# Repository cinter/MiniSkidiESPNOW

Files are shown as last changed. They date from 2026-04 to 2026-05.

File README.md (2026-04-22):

# MiniSkidiESPNOW
Branch of ProfBoots MiniSkidi code to support a custom controller with control via ESPNOW wifi. The code uploaded here will be working code, so don't worry if there are few commits. I use this repo as a backup of known good states. I am not a coder, this is all generated with Gemini and checked by Codex.

## 3D files
The original controller design can be found on OnShape [here](https://cad.onshape.com/documents/6bafb625ffbc5bb075599570/w/3596931d871cc26ccb4a224e/e/206217da13ada2750408ef04).

Printable files are [here](https://www.printables.com/model/1694698-miniskidi-controller), and I'll try to keep a list of components below.

## Components
Custom circuit board: KiCad files can be downloaded from Controller_V2 here. Ordered from JLCPCB, but PCBWay and others work too.  
Joystick: [Analog 2-axis Thumb Joystick with Select Button + Breakout Board](https://thepihut.com/products/adafruit-analog-2-axis-thumb-joystick-with-select-button-breakout-board)  
ESP32-C3 XIAO dev board: [Seeed XIAO ESP32C3](https://thepihut.com/products/seeed-xiao-esp32c3?variant=53975115694465)  
Battery: [3.7V 600mAh Battery](https://www.amazon.co.uk/dp/B0DB1X3RK7)  
Toggle switch: [5mm	toggle](https://www.amazon.co.uk/dp/B088R3GYWP)  
Tacctile buttons: [PCB buttons, these or similar](https://www.mouser.co.uk/ProductDetail/Same-Sky/TS04-66-85-BK-160-SMT-TR?qs=VJzv269c%252BPaHwNn0xD14PA%3D%3D)  
LED: [Neopixel LED](https://thepihut.com/products/neopixel-5050-rgb-led-with-integrated-driver-chip-10-pack)  
Cap for NeoPixel: [0.1uF Capacitor](https://uk.farnell.com/vishay/k104k15x7rf5tl2/cap-0-1-f-50v-10-x7r/dp/2860097)  
Light pipe:	[3mm, 1mm length](https://uk.farnell.com/mentor/1282-1405/light-pipe-1pipe-11mm-l-panel/dp/4562818)

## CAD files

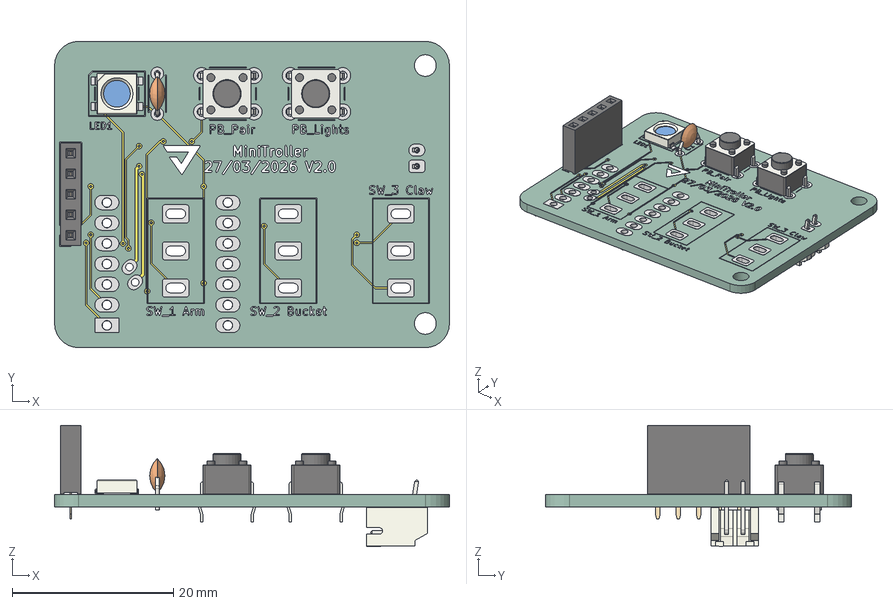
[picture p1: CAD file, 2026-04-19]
Controller_V2/Controller_V2.step
49.0 x 38.0 x 15.0 mm
C_Disc_D4.3mm_W1.9mm_P5.00mm
PinSocket_1x05_P2.54mm_Vertical
LED_Inolux_IN-PI554FCH_PLCC4_5.0x5.0mm_P3.2mm
SW_PUSH_6mm_H5mm x 2
JST_PH_S2B-PH-K_1x02_P2.00mm_Horizontal
Controller_V2_copper
Controller_V2_pad
Controller_V2_via
Controller_V2_silkscreen x 2
Controller_V2_PCB

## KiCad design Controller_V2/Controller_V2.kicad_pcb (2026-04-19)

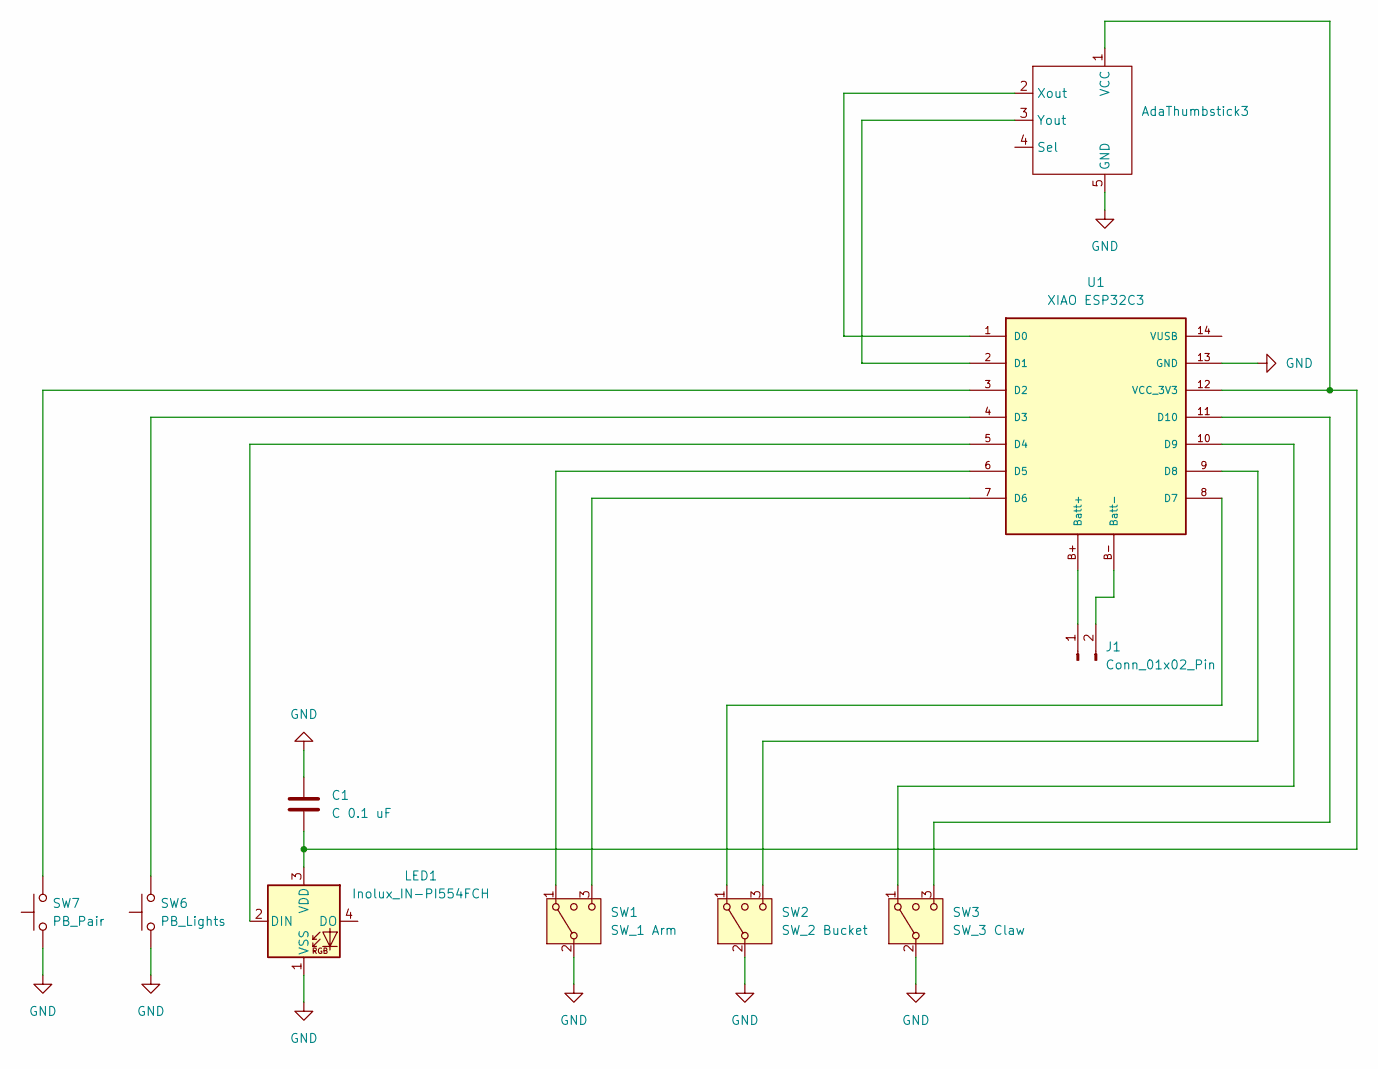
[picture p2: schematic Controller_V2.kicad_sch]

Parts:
AdaThumbstick3: PinSocket_1x05_P2.54mm_Vertical
C1: C 0.1 uF; C_Disc_D4.3mm_W1.9mm_P5.00mm
J1: Conn_01x02_Pin; JST_PH_S2B-PH-K_1x02_P2.00mm_Horizontal
LED1: Inolux_IN-PI554FCH; LED_Inolux_IN-PI554FCH_PLCC4_5.0x5.0mm_P3.2mm
SW1: SW_1 Arm; Toggle switch
SW2: SW_2 Bucket; Toggle switch
SW3: SW_3 Claw; Toggle switch
SW6: PB_Lights; SW_PUSH_6mm_H5mm
SW7: PB_Pair; SW_PUSH_6mm_H5mm
U1: XIAO ESP32C3

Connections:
GND: AdaThumbstick3.5 (GND), C1.1, LED1.1 (VSS), SW1.2 (3), SW2.2 (3), SW3.2 (3), SW6.1, SW7.1, U1.13 (GND)
unnamed: AdaThumbstick3.1 (VCC), C1.2, LED1.3 (VDD), U1.12 (VCC_3V3)
unnamed: AdaThumbstick3.2 (Xout), U1.1 (D0)
unnamed: AdaThumbstick3.3 (Yout), U1.2 (D1)
unnamed: J1.1, U1.B+ (Batt+)
unnamed: J1.2, U1.B- (Batt-)
unnamed: LED1.2 (DIN), U1.5 (D4)
unnamed: SW1.3 (4), U1.7 (D6)
unnamed: SW2.3 (4), U1.9 (D8)
unnamed: SW3.3 (4), U1.11 (D10)
unnamed: SW7.2, U1.3 (D2)
unnamed: SW6.2, U1.4 (D3)
unnamed: SW1.1, U1.6 (D5)
unnamed: SW2.1, U1.8 (D7)
unnamed: SW3.1, U1.10 (D9)

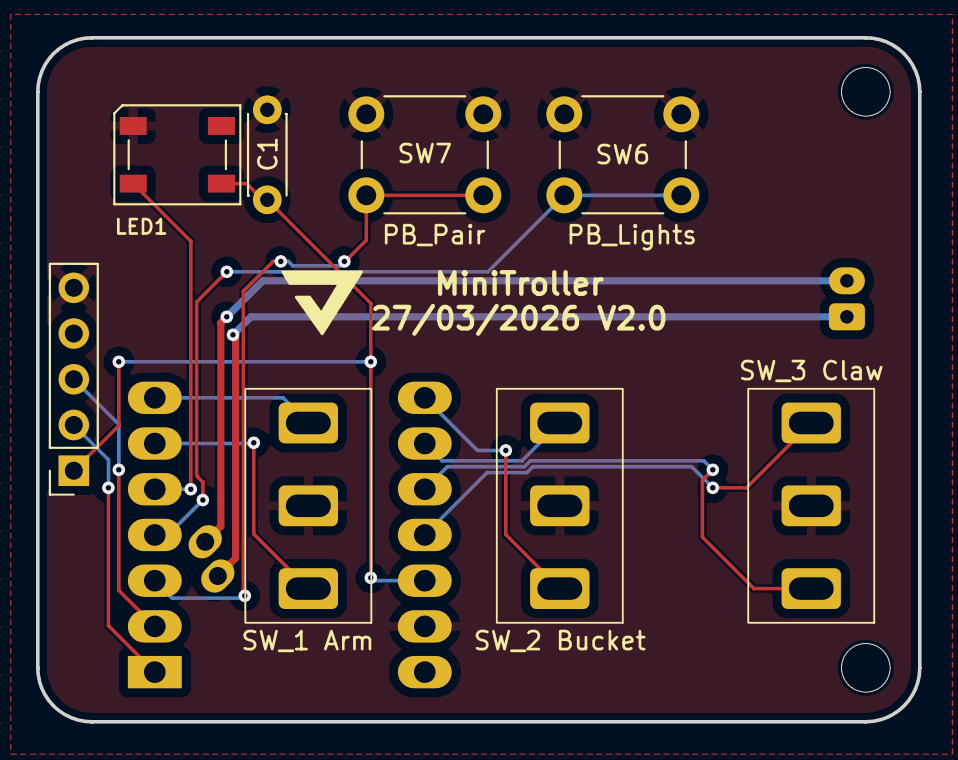
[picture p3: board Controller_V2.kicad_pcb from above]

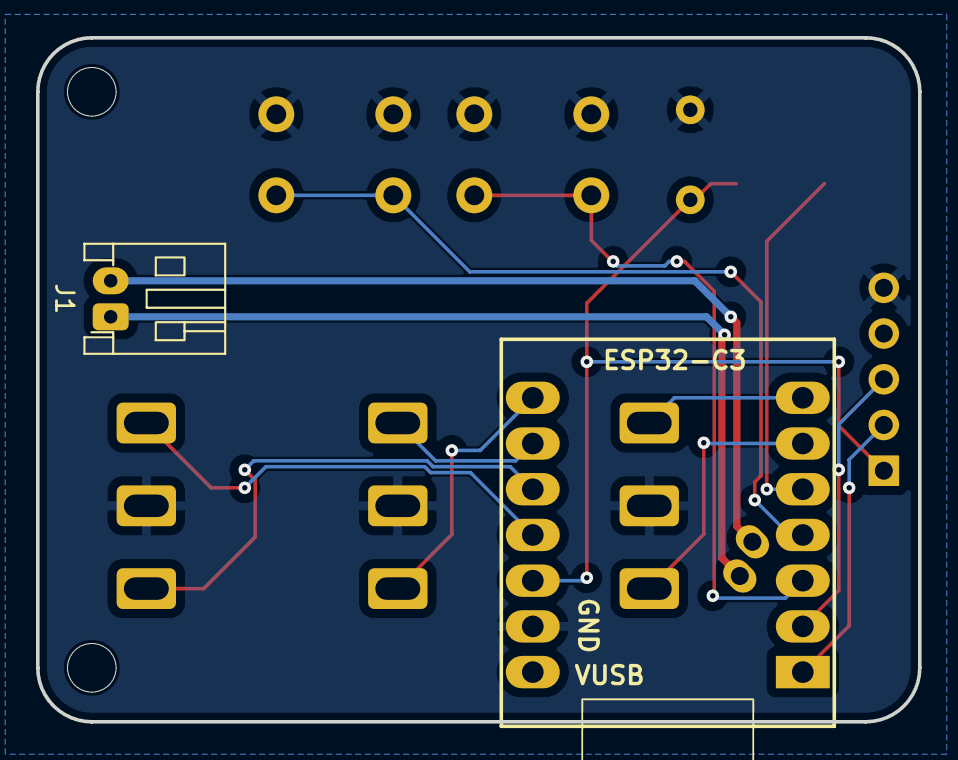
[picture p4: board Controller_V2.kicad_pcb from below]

Board: 2 copper layers, 49.0 x 38.0 mm, 10 parts (2 on the bottom side), 15 nets.

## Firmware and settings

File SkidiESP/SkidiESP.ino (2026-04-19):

#include <Arduino.h>
#include <WiFi.h>
#include <esp_now.h>
#include <esp_wifi.h>
#include <ESP32Servo.h>
#include <driver/mcpwm.h>
#include <ESP32_MCPWM.h>

// ======================================================
// Pin definitions
// ======================================================
#define bucketServoPin 23
#define auxServoPin    22

#define lightPin1      18
#define lightPin2      5

#define rightMotor0    25   // motor input A
#define rightMotor1    26   // motor input B

#define leftMotor0     33   // motor input A
#define leftMotor1     32   // motor input B

#define armMotor0      21
#define armMotor1      19

#ifndef LED_BUILTIN
#define LED_BUILTIN 2
#endif

// ======================================================
// Shared packet definition
// ======================================================
struct __attribute__((packed)) ControlPacket
{
  int16_t x;      // -1000 to +1000
  int16_t y;      // -1000 to +1000
  uint8_t sw1_A;
  uint8_t sw1_B;
  uint8_t sw2_A;
  uint8_t sw2_B;
  uint8_t sw3_A;
  uint8_t sw3_B;
  uint8_t lightsOn;
};

// ======================================================
// 🔄 INVERSION / POLARITY TUNABLES (Change 1 to -1 to flip)
// ======================================================
const int INVERT_LEFT_MOTOR  = -1;
const int INVERT_RIGHT_MOTOR = -1;
const int INVERT_ARM_MOTOR   = 1;
const int INVERT_BUCKET      = -1;
const int INVERT_AUX         = -1;

// ======================================================
// Tunables
// ======================================================
const uint32_t CONTROL_PERIOD_US     = 20000;  // 50 Hz
const uint32_t SERVO_STEP_PERIOD_US  = 20000;  // 50 Hz servo stepping
const unsigned long DEBUG_PERIOD_MS  = 500;
const unsigned long FAILSAFE_MS      = 150;
const unsigned long PAIR_WINDOW_MS   = 4000;
const unsigned long PAIR_INTERVAL_MS = 250;

const unsigned long HEARTBEAT_INTERVAL_MS      = 250;
const unsigned long HEARTBEAT_ACTIVE_WINDOW_MS = 500;

// Joystick thresholds
const int STOP_DEADZONE   = 80;
const int DRIVE_DEADZONE  = 140;
const int STEER_DEADZONE  = 180;
const int HARD_TURN_ZONE  = 650;

// Servo tuning
const int SERVO_MIN_ANGLE_B    = 5;
const int SERVO_MAX_ANGLE_B    = 150;
const int SERVO_MIN_ANGLE_AUX  = 45;
const int SERVO_MAX_ANGLE_AUX  = 180;
const int SERVO_STEP           = 4;

// Drive tuning
const int MOTOR_INPUT_MAX        = 1000;
const int MOTOR_OUTPUT_DEADZONE  = 35;
const int STEER_GAIN_PERCENT     = 80;

// Ramp / smoothing
const int MOTOR_SLEW_UP_STEP     = 80;  // per control tick
const int MOTOR_SLEW_DOWN_STEP   = 50;  // per control tick

// MCPWM / library tuning
const int MOTOR_PWM_FREQ_HZ       = 20000;
const bool USE_CENTER_ALIGNED_PWM = true;

// ======================================================
// Globals
// ======================================================
Servo bucketServo;
Servo auxServo;

Motor leftDriveMotor;
Motor rightDriveMotor;

portMUX_TYPE controlMux = portMUX_INITIALIZER_UNLOCKED;
portMUX_TYPE peerMux    = portMUX_INITIALIZER_UNLOCKED;
portMUX_TYPE statusMux  = portMUX_INITIALIZER_UNLOCKED;

ControlPacket controlData = {0, 0, 0, 0, 0, 0, 0, 0, 0};

volatile unsigned long packetCount = 0;
volatile unsigned long lastPacketTime = 0;
volatile bool hasValidPacket = false;

// Communication status / deferred debug work
volatile bool rxPulseRequested = false;
volatile bool wrongRxSizeFlag = false;
volatile int wrongRxSizeLen = 0;

// Controller peer tracking
uint8_t controllerMAC[6] = {0};
uint8_t pendingControllerMAC[6] = {0};
bool controllerPeerKnown = false;
bool pendingControllerMACReady = false;
unsigned long lastHeartbeatSend = 0;

// Servo state
int bucketServoValue = 140;
int auxServoValue = 150;

// Drive state
int leftTargetCmd = 0;
int rightTargetCmd = 0;
int leftCurrentCmd = 0;
int rightCurrentCmd = 0;

// Debug/status
bool debugLedEnabled = true;
unsigned long ledPulseUntil = 0;
unsigned long lastDebugPrint = 0;

// Pairing
const uint8_t broadcastAddress[] = {0xFF, 0xFF, 0xFF, 0xFF, 0xFF, 0xFF};
bool pairingWindowActive = true;
unsigned long pairingWindowStart = 0;
unsigned long lastPairSend = 0;

// Scheduler
uint32_t nextControlTickUs = 0;
uint32_t nextServoTickUs = 0;

// ======================================================
// Helpers
// ======================================================
int applyDeadzone(int value, int deadzone)
{
  if (abs(value) < deadzone) return 0;
  return value;
}

int slewToward(int current, int target, int upStep, int downStep)
{
  int maxStep = (abs(target) > abs(current)) ? upStep : downStep;
  int delta = target - current;
  delta = constrain(delta, -maxStep, maxStep);
  return current + delta;
}

void printReceiverMac()
{
  uint8_t mac[6];
  if (esp_wifi_get_mac(WIFI_IF_STA, mac) == ESP_OK)
  {
    Serial.printf(
      "Receiver STA MAC: %02X:%02X:%02X:%02X:%02X:%02X\n",
      mac[0], mac[1], mac[2], mac[3], mac[4], mac[5]
    );
  }
  else
  {
    Serial.println("Receiver STA MAC: unavailable");
  }
}

void pulseDebugLed()
{
  if (!debugLedEnabled) return;
  digitalWrite(LED_BUILTIN, HIGH);
  ledPulseUntil = millis() + 40;
}

void updateDebugLed()
{
  if (!debugLedEnabled) return;

  if (ledPulseUntil != 0 && millis() >= ledPulseUntil)
  {
    digitalWrite(LED_BUILTIN, LOW);
    ledPulseUntil = 0;
  }
}

void processDeferredCommStatus()
{
  bool doPulse = false;
  bool printWrongSize = false;
  int wrongSize = 0;

  portENTER_CRITICAL(&statusMux);
  if (rxPulseRequested)
  {
    doPulse = true;
    rxPulseRequested = false;
  }

  if (wrongRxSizeFlag)
  {
    printWrongSize = true;
    wrongSize = wrongRxSizeLen;
    wrongRxSizeFlag = false;
  }
  portEXIT_CRITICAL(&statusMux);

  if (doPulse)
  {
    pulseDebugLed();
  }

  if (printWrongSize)
  {
    Serial.printf("RX wrong size: got %d expected %u\n", wrongSize, (unsigned)sizeof(ControlPacket));
  }
}

void setLights(bool on)
{
  if (on)
  {
    digitalWrite(lightPin1, HIGH);
    digitalWrite(lightPin2, LOW);
  }
  else
  {
    digitalWrite(lightPin1, LOW);
    digitalWrite(lightPin2, LOW);
  }
}

void writeBucketServo()
{
  bucketServo.write(bucketServoValue);
}

void writeAuxServo()
{
  auxServo.write(auxServoValue);
}

bool macEquals(const uint8_t *a, const uint8_t *b)
{
  return memcmp(a, b, 6) == 0;
}

// ======================================================
// ESP-NOW
// ======================================================
void OnDataRecv(const esp_now_recv_info *info, const uint8_t *incomingData, int len)
{
  if (len == (int)sizeof(ControlPacket))
  {
    portENTER_CRITICAL(&controlMux);
    memcpy(&controlData, incomingData, sizeof(ControlPacket));
    lastPacketTime = millis();
    hasValidPacket = true;
    packetCount++;
    portEXIT_CRITICAL(&controlMux);

    portENTER_CRITICAL(&peerMux);
    memcpy(pendingControllerMAC, info->src_addr, sizeof(pendingControllerMAC));
    pendingControllerMACReady = true;
    portEXIT_CRITICAL(&peerMux);

    portENTER_CRITICAL(&statusMux);
    rxPulseRequested = true;
    portEXIT_CRITICAL(&statusMux);
  }
  else
  {
    portENTER_CRITICAL(&statusMux);
    wrongRxSizeLen = len;
    wrongRxSizeFlag = true;
    portEXIT_CRITICAL(&statusMux);
  }
}

void sendPairPacket()
{
  const uint8_t pairPayload[] = {'P', 'A', 'I', 'R'};
  esp_now_send(broadcastAddress, pairPayload, sizeof(pairPayload));
}

void updateStartupPairing()
{
  if (!pairingWindowActive) return;

  unsigned long now = millis();

  if (now - pairingWindowStart >= PAIR_WINDOW_MS)
  {
    pairingWindowActive = false;
    return;
  }

  if (now - lastPairSend >= PAIR_INTERVAL_MS)
  {
    sendPairPacket();
    lastPairSend = now;
  }
}

void processPendingControllerPeer()
{
  uint8_t newMAC[6] = {0};
  bool hasPending = false;

  portENTER_CRITICAL(&peerMux);
  if (pendingControllerMACReady)
  {
    memcpy(newMAC, pendingControllerMAC, sizeof(newMAC));
    pendingControllerMACReady = false;
    hasPending = true;
  }
  portEXIT_CRITICAL(&peerMux);

  if (!hasPending)
  {
    return;
  }

  if (controllerPeerKnown && macEquals(controllerMAC, newMAC))
  {
    return;
  }

  if (controllerPeerKnown && esp_now_is_peer_exist(controllerMAC))
  {
    esp_now_del_peer(controllerMAC);
  }

  esp_now_peer_info_t peerInfo = {};
  memcpy(peerInfo.peer_addr, newMAC, sizeof(newMAC));
  peerInfo.channel = 0;
  peerInfo.encrypt = false;

  if (esp_now_add_peer(&peerInfo) == ESP_OK)
  {
    memcpy(controllerMAC, newMAC, sizeof(controllerMAC));
    controllerPeerKnown = true;

    Serial.printf(
      "Controller peer set to %02X:%02X:%02X:%02X:%02X:%02X\n",
      controllerMAC[0], controllerMAC[1], controllerMAC[2],
      controllerMAC[3], controllerMAC[4], controllerMAC[5]
    );
  }
  else
  {
    controllerPeerKnown = false;
    memset(controllerMAC, 0, sizeof(controllerMAC));
    Serial.println("Controller peer add failed");
  }
}

void sendHeartbeatIfDue()
{
  if (!controllerPeerKnown)
  {
    return;
  }

  const unsigned long now = millis();
  if (now - lastHeartbeatSend < HEARTBEAT_INTERVAL_MS)
  {
    return;
  }

  unsigned long localLastPacketTime;
  bool localHasValidPacket;

  portENTER_CRITICAL(&controlMux);
  localLastPacketTime = lastPacketTime;
  localHasValidPacket = hasValidPacket;
  portEXIT_CRITICAL(&controlMux);

  if (!localHasValidPacket)
  {
    return;
  }

  if (now - localLastPacketTime > HEARTBEAT_ACTIVE_WINDOW_MS)
  {
    return;
  }

  const uint8_t hbPayload[] = {'H', 'B'};
  esp_now_send(controllerMAC, hbPayload, sizeof(hbPayload));
  lastHeartbeatSend = now;
}

// ======================================================
// Motor backend
// ======================================================
void applySignedMotorCommand(Motor &motor, int signedCmd, int polarity)
{
  int cmd = constrain(signedCmd * polarity, -MOTOR_INPUT_MAX, MOTOR_INPUT_MAX);

  if (abs(cmd) <= MOTOR_OUTPUT_DEADZONE)
  {
    motor.setSpeed(0, Dir::CW);
    return;
  }

  if (cmd > 0)
  {
    motor.setSpeed(cmd, Dir::CW);
  }
  else
  {
    motor.setSpeed(-cmd, Dir::CCW);
  }
}

void stopDriveMotors()
{
  leftTargetCmd = 0;
  rightTargetCmd = 0;
  leftCurrentCmd = 0;
  rightCurrentCmd = 0;

  leftDriveMotor.setSpeed(0, Dir::CW);
  rightDriveMotor.setSpeed(0, Dir::CW);
}

void setArmMotor(int direction)
{
  direction = direction * INVERT_ARM_MOTOR;

  if (direction > 0)
  {
    digitalWrite(armMotor0, LOW);
    digitalWrite(armMotor1, HIGH);
  }
  else if (direction < 0)
  {
    digitalWrite(armMotor0, HIGH);
    digitalWrite(armMotor1, LOW);
  }
  else
  {
    digitalWrite(armMotor0, LOW);
    digitalWrite(armMotor1, LOW);
  }
}

void stopArmMotor()
{
  setArmMotor(0);
}

// ======================================================
// Control logic
// ======================================================
void computeDriveTargets(int x, int y, int &leftOut, int &rightOut)
{
  int throttle = applyDeadzone(constrain(y, -1000, 1000), DRIVE_DEADZONE);
  int steering = applyDeadzone(constrain(x, -1000, 1000), STEER_DEADZONE);

  steering = (steering * STEER_GAIN_PERCENT) / 100;

  int leftCmd  = throttle + steering;
  int rightCmd = throttle - steering;

  leftCmd = constrain(leftCmd, -1000, 1000);
  rightCmd = constrain(rightCmd, -1000, 1000);

  if (abs(x) < STOP_DEADZONE && abs(y) < STOP_DEADZONE)
  {
    leftCmd = 0;
    rightCmd = 0;
  }

  if (abs(throttle) < DRIVE_DEADZONE && abs(x) > HARD_TURN_ZONE)
  {
    int pivot = map(abs(x), HARD_TURN_ZONE, 1000, 650, 1000);
    pivot = constrain(pivot, 0, 1000);

    if (x > 0)
    {
      leftCmd  = pivot;
      rightCmd = -pivot;
    }
    else
    {
      leftCmd  = -pivot;
      rightCmd = pivot;
    }
  }

  leftOut = leftCmd;
  rightOut = rightCmd;
}

void updateDriveFromJoystick(int x, int y)
{
  computeDriveTargets(x, y, leftTargetCmd, rightTargetCmd);

  leftCurrentCmd = slewToward(leftCurrentCmd, leftTargetCmd, MOTOR_SLEW_UP_STEP, MOTOR_SLEW_DOWN_STEP);
  rightCurrentCmd = slewToward(rightCurrentCmd, rightTargetCmd, MOTOR_SLEW_UP_STEP, MOTOR_SLEW_DOWN_STEP);

  applySignedMotorCommand(leftDriveMotor, leftCurrentCmd, INVERT_LEFT_MOTOR);
  applySignedMotorCommand(rightDriveMotor, rightCurrentCmd, INVERT_RIGHT_MOTOR);
}

void updateArmFromSwitches(const ControlPacket &data)
{
  if (data.sw1_A && !data.sw1_B)
  {
    setArmMotor(1);
  }
  else if (data.sw1_B && !data.sw1_A)
  {
    setArmMotor(-1);
  }
  else
  {
    stopArmMotor();
  }
}

void updateServosFromSwitches(const ControlPacket &data)
{
  int bucketMove = 0;
  if (data.sw2_A && !data.sw2_B) bucketMove = 1;
  else if (data.sw2_B && !data.sw2_A) bucketMove = -1;

  if (bucketMove != 0)
  {
    bucketServoValue += (bucketMove * SERVO_STEP * INVERT_BUCKET);
    bucketServoValue = constrain(bucketServoValue, SERVO_MIN_ANGLE_B, SERVO_MAX_ANGLE_B);
    writeBucketServo();
  }

  int auxMove = 0;
  if (data.sw3_A && !data.sw3_B) auxMove = 1;
  else if (data.sw3_B && !data.sw3_A) auxMove = -1;

  if (auxMove != 0)
  {
    auxServoValue += (auxMove * SERVO_STEP * INVERT_AUX);
    auxServoValue = constrain(auxServoValue, SERVO_MIN_ANGLE_AUX, SERVO_MAX_ANGLE_AUX);
    writeAuxServo();
  }
}

void applyFailsafe()
{
  stopDriveMotors();
  stopArmMotor();
  // Hold current servo positions
  // Leave lights in last commanded state
}

void readControlSnapshot(ControlPacket &localData,
                         unsigned long &localLastPacketTime,
                         bool &localHasValidPacket)
{
  portENTER_CRITICAL(&controlMux);
  memcpy(&localData, &controlData, sizeof(ControlPacket));
  localLastPacketTime = lastPacketTime;
  localHasValidPacket = hasValidPacket;
  portEXIT_CRITICAL(&controlMux);
}

void updateControl()
{
  ControlPacket localData;
  unsigned long localLastPacketTime;
  bool localHasValidPacket;

  readControlSnapshot(localData, localLastPacketTime, localHasValidPacket);

  if (!localHasValidPacket || (millis() - localLastPacketTime > FAILSAFE_MS))
  {
    applyFailsafe();
    return;
  }

  setLights(localData.lightsOn);
  updateDriveFromJoystick(localData.x, localData.y);
  updateArmFromSwitches(localData);
}

void updateServoControl()
{
  ControlPacket localData;
  unsigned long localLastPacketTime;
  bool localHasValidPacket;

  readControlSnapshot(localData, localLastPacketTime, localHasValidPacket);

  if (!localHasValidPacket || (millis() - localLastPacketTime > FAILSAFE_MS))
  {
    return;
  }

  updateServosFromSwitches(localData);
}

// ======================================================
// Debug
// ======================================================
void printDebugStatus()
{
  if (millis() - lastDebugPrint < DEBUG_PERIOD_MS) return;
  lastDebugPrint = millis();

  ControlPacket localData;
  unsigned long localLastPacketTime;
  bool localHasValidPacket;
  unsigned long localPacketCount;

  portENTER_CRITICAL(&controlMux);
  memcpy(&localData, &controlData, sizeof(ControlPacket));
  localLastPacketTime = lastPacketTime;
  localHasValidPacket = hasValidPacket;
  localPacketCount = packetCount;
  portEXIT_CRITICAL(&controlMux);

  Serial.printf(
    "Packets=%lu | valid=%d | age=%lu ms | x=%d y=%d | LT=%d RT=%d | LC=%d RC=%d | sw1(%u,%u) sw2(%u,%u) sw3(%u,%u) | light=%u | bucket=%d aux=%d | peer=%d\n",
    localPacketCount,
    localHasValidPacket,
    millis() - localLastPacketTime,
    localData.x,
    localData.y,
    leftTargetCmd,
    rightTargetCmd,
    leftCurrentCmd,
    rightCurrentCmd,
    localData.sw1_A, localData.sw1_B,
    localData.sw2_A, localData.sw2_B,
    localData.sw3_A, localData.sw3_B,
    localData.lightsOn,
    bucketServoValue,
    auxServoValue,
    controllerPeerKnown
  );
}

// ======================================================
// Setup helpers
// ======================================================
void setupPins()
{
  pinMode(armMotor0, OUTPUT);
  pinMode(armMotor1, OUTPUT);

  pinMode(lightPin1, OUTPUT);
  pinMode(lightPin2, OUTPUT);

  stopArmMotor();
  setLights(false);
}

void setupServos()
{
  ESP32PWM::allocateTimer(0);
  ESP32PWM::allocateTimer(1);
  ESP32PWM::allocateTimer(2);
  ESP32PWM::allocateTimer(3);

  bucketServo.setPeriodHertz(50);
  auxServo.setPeriodHertz(50);

  bucketServo.attach(bucketServoPin, 500, 2400);
  auxServo.attach(auxServoPin, 500, 2400);

  writeBucketServo();
  writeAuxServo();
}

void setupDriveMotors()
{
  MotorMCPWMConfig rightHw{
    rightMotor0,
    rightMotor1,
    -1,
    MCPWM_UNIT_0,
    MCPWM_TIMER_0,
    MCPWM0A,
    MCPWM0B
  };

  MotorMCPWMConfig leftHw{
    leftMotor0,
    leftMotor1,
    -1,
    MCPWM_UNIT_1,
    MCPWM_TIMER_0,
    MCPWM0A,
    MCPWM0B
  };

  rightHw.pwm_freq_hz = MOTOR_PWM_FREQ_HZ;
  leftHw.pwm_freq_hz  = MOTOR_PWM_FREQ_HZ;

  rightHw.input_max = MOTOR_INPUT_MAX;
  leftHw.input_max  = MOTOR_INPUT_MAX;

  rightHw.counter = USE_CENTER_ALIGNED_PWM ? MCPWM_UP_DOWN_COUNTER : MCPWM_UP_COUNTER;
  leftHw.counter  = USE_CENTER_ALIGNED_PWM ? MCPWM_UP_DOWN_COUNTER : MCPWM_UP_COUNTER;

  rightHw.use_deadtime = false;
  leftHw.use_deadtime  = false;

  MotorBehaviorConfig behavior{
    FreewheelMode::HiZ_Awake,
    60,    // soft_brake_hz
    0,     // dither_pwm
    0,     // default_soft
    600,   // min_phase_us
    true   // dither_coast_hi_z
  };

  leftDriveMotor.setup(leftHw, behavior);
  rightDriveMotor.setup(rightHw, behavior);

  stopDriveMotors();
}

bool setupEspNow()
{
  WiFi.mode(WIFI_STA);
  WiFi.disconnect();

  printReceiverMac();
  Serial.printf("ControlPacket size = %u bytes\n", (unsigned)sizeof(ControlPacket));
  Serial.printf("MOTOR_PWM_FREQ_HZ = %d\n", MOTOR_PWM_FREQ_HZ);

  if (esp_now_init() != ESP_OK)
  {
    Serial.println("ESP-NOW init failed");
    return false;
  }

  esp_now_register_recv_cb(OnDataRecv);

  esp_now_peer_info_t peerInfo = {};
  memcpy(peerInfo.peer_addr, broadcastAddress, 6);
  peerInfo.channel = 0;
  peerInfo.encrypt = false;

  if (!esp_now_is_peer_exist((uint8_t *)broadcastAddress))
  {
    if (esp_now_add_peer(&peerInfo) != ESP_OK)
    {
      Serial.println("Broadcast peer add failed");
      return false;
    }
  }

  return true;
}

// ======================================================
// Setup / Loop
// ======================================================
void setup()
{
  Serial.begin(115200);

  pinMode(LED_BUILTIN, OUTPUT);
  digitalWrite(LED_BUILTIN, LOW);

  setupPins();
  setupServos();
  setupDriveMotors();

  if (!setupEspNow())
  {
    Serial.println("Receiver setup halted");
    while (true)
    {
      updateDebugLed();
    }
  }

  pairingWindowStart = millis();
  lastPairSend = 0;
  pairingWindowActive = true;
  lastHeartbeatSend = 0;

  nextControlTickUs = micros() + CONTROL_PERIOD_US;
  nextServoTickUs   = micros() + SERVO_STEP_PERIOD_US;

  Serial.println("Receiver ready");
}

void loop()
{
  uint32_t nowUs = micros();

  if ((int32_t)(nowUs - nextControlTickUs) >= 0)
  {
    nextControlTickUs += CONTROL_PERIOD_US;
    updateControl();
  }

  if ((int32_t)(nowUs - nextServoTickUs) >= 0)
  {
    nextServoTickUs += SERVO_STEP_PERIOD_US;
    updateServoControl();
  }

  updateStartupPairing();
  processPendingControllerPeer();
  sendHeartbeatIfDue();
  processDeferredCommStatus();
  updateDebugLed();
  printDebugStatus();
}

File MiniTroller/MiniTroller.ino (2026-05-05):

#include <esp_now.h>
#include <WiFi.h>
#include <esp_wifi.h>
#include <Preferences.h>
#include <Adafruit_NeoPixel.h>
#include <esp_system.h>

// =====================
// Debug configuration
// =====================
// Set to 0 for normal use after testing.
#define DEBUG_ENABLED 1

constexpr unsigned long debugInputInterval = 500UL;

#if DEBUG_ENABLED
  #define DBG_BEGIN(baud) Serial.begin(baud)
  #define DBG_PRINTLN(...) Serial.println(__VA_ARGS__)
  #define DBG_PRINTF(...) Serial.printf(__VA_ARGS__)
#else
  #define DBG_BEGIN(baud) do {} while (false)
  #define DBG_PRINTLN(...) do {} while (false)
  #define DBG_PRINTF(...) do {} while (false)
#endif

Preferences preferences;

// --- Pin Definitions (Seeed Studio XIAO ESP32-C3) ---
constexpr int pinX      = 2;
constexpr int pinY      = 3;
constexpr int btnPower  = 4;
constexpr int btnLights = 5;
constexpr int neoPin    = 6;
constexpr int sw1_A     = 7;
constexpr int sw1_B     = 21;
constexpr int sw2_A     = 20;
constexpr int sw2_B     = 8;
constexpr int sw3_A     = 9;
constexpr int sw3_B     = 10;

Adafruit_NeoPixel pixel(1, neoPin, NEO_GRB + NEO_KHZ800);

// --- System Variables ---
RTC_DATA_ATTR int crashCounter = 0;

enum SystemState { IDLE, PAIRING, PAIRED };
SystemState currentState = IDLE;

uint8_t receiverMAC[6] = {0};
esp_now_peer_info_t peerInfo = {};

portMUX_TYPE pairingMux = portMUX_INITIALIZER_UNLOCKED;
bool pairingComplete = false;
uint8_t pendingPeerMAC[6] = {0};

volatile unsigned long lastVehicleHeartbeatTime = 0;

unsigned long lastActivityTime = 0;
constexpr unsigned long sleepTimeout = 300000UL;
constexpr unsigned long pairingTimeout = 30000UL;
constexpr unsigned long vehicleHeartbeatTimeout = 1500UL;

unsigned long lastSendTime = 0;
unsigned long pairingStartTime = 0;
unsigned long lastLedUpdate = 0;
unsigned long lastDebugInputPrint = 0;

unsigned long btnPowerPressTime = 0;
unsigned long btnLightsPressTime = 0;

bool isPowerBtnHeld = false;
bool isLightsBtnHeld = false;
bool lightsLongPressHandled = false;

bool lightsAreOn = false;
int activeReceiverSlot = 1;

constexpr unsigned long debounceDelay = 25UL;
constexpr unsigned long holdTime = 2000UL;

bool powerBtnRawState = HIGH;
bool powerBtnStableState = HIGH;
bool lastPowerBtnRawState = HIGH;
unsigned long lastPowerBtnDebounceTime = 0;

bool lightsBtnRawState = HIGH;
bool lightsBtnStableState = HIGH;
bool lastLightsBtnRawState = HIGH;
unsigned long lastLightsBtnDebounceTime = 0;

bool lastPowerBtnPressed = false;
bool lastLightsBtnPressed = false;

int centerX = 2048;
int centerY = 2048;
int smoothX = 0;
int smoothY = 0;

constexpr int joystickDeadzone = 40;
constexpr int joystickActivityThreshold = 150;

struct __attribute__((packed)) ControlPacket {
  int16_t x;
  int16_t y;
  uint8_t sw1_A;
  uint8_t sw1_B;
  uint8_t sw2_A;
  uint8_t sw2_B;
  uint8_t sw3_A;
  uint8_t sw3_B;
  uint8_t lightsOn;
};

ControlPacket controlData = {};

const char *stateName(SystemState state) {
  switch (state) {
    case IDLE:    return "IDLE";
    case PAIRING: return "PAIRING";
    case PAIRED:  return "PAIRED";
    default:      return "UNKNOWN";
  }
}

void printMAC(const uint8_t mac[6]) {
#if DEBUG_ENABLED
  Serial.printf("%02X:%02X:%02X:%02X:%02X:%02X",
                mac[0], mac[1], mac[2], mac[3], mac[4], mac[5]);
#endif
}

void logState(const char *message) {
#if DEBUG_ENABLED
  Serial.printf("[%lu] %s | state=%s slot=%d lights=%s\n",
                millis(), message, stateName(currentState), activeReceiverSlot,
                lightsAreOn ? "ON" : "OFF");
#endif
}

void slotColour(uint8_t slot, uint8_t &r, uint8_t &g, uint8_t &b) {
  if (slot == 1) {
    r = 255;
    g = 150;
    b = 0;
  } else {
    r = 0;
    g = 255;
    b = 0;
  }
}

// --- ESP-NOW Callbacks ---
void OnDataRecv(const esp_now_recv_info *recv_info, const uint8_t *incomingData, int len) {
  if (recv_info == nullptr || incomingData == nullptr) {
    return;
  }

  if (len == 4 && memcmp(incomingData, "PAIR", 4) == 0) {
    portENTER_CRITICAL(&pairingMux);
    memcpy(pendingPeerMAC, recv_info->src_addr, sizeof(pendingPeerMAC));
    pairingComplete = true;
    portEXIT_CRITICAL(&pairingMux);
    return;
  }

  if (len == 2 && memcmp(incomingData, "HB", 2) == 0) {
    lastVehicleHeartbeatTime = millis();
    return;
  }
}

void OnDataSent(const wifi_tx_info_t *txInfo, esp_now_send_status_t status) {
#if DEBUG_ENABLED
  static esp_now_send_status_t lastStatus = ESP_NOW_SEND_SUCCESS;

  if (status != lastStatus) {
    Serial.printf("[%lu] ESP-NOW send status changed: %s",
                  millis(),
                  status == ESP_NOW_SEND_SUCCESS ? "SUCCESS" : "FAIL");

    if (txInfo != nullptr) {
      Serial.print(" peer=");
      printMAC(txInfo->des_addr);
    }

    Serial.println();
    lastStatus = status;
  }
#else
  (void)txInfo;
  (void)status;
#endif
}

// --- Logic Functions ---
void enterPairingMode(unsigned long now) {
  DBG_PRINTF("[%lu] Clearing slot %d and entering pairing mode\n", now, activeReceiverSlot);

  const char *key = (activeReceiverSlot == 1) ? "peer_mac_1" : "peer_mac_2";
  preferences.remove(key);

  if (esp_now_is_peer_exist(receiverMAC)) {
    esp_now_del_peer(receiverMAC);
  }

  memset(receiverMAC, 0, sizeof(receiverMAC));

  portENTER_CRITICAL(&pairingMux);
  pairingComplete = false;
  memset(pendingPeerMAC, 0, sizeof(pendingPeerMAC));
  portEXIT_CRITICAL(&pairingMux);

  lastVehicleHeartbeatTime = 0;
  currentState = PAIRING;
  pairingStartTime = now;
}

void writeStatusLED() {
  const unsigned long now = millis();

  if (now - lastLedUpdate < 50UL) {
    return;
  }
  lastLedUpdate = now;

  uint8_t r = 0;
  uint8_t g = 0;
  uint8_t b = 0;
  bool isOn = true;

  slotColour(activeReceiverSlot, r, g, b);

  bool heartbeatTimedOut = false;

  if (currentState == PAIRED) {
    const unsigned long hbTime = lastVehicleHeartbeatTime;

    if (hbTime == 0) {
      heartbeatTimedOut = true;
    } else if (hbTime <= now) {
      heartbeatTimedOut = (now - hbTime > vehicleHeartbeatTimeout);
    } else {
      // millis() wrapped or callback updated hbTime after this loop iteration started.
      // Treat as fresh rather than declaring a false timeout.
      heartbeatTimedOut = false;
    }
  }

  if (currentState == PAIRING) {
    // Fast blink in the selected slot colour while listening for a receiver.
    isOn = ((now / 150UL) % 2UL) != 0UL;
  } else if (currentState == IDLE) {
    // Empty active slot: short periodic blink in the selected slot colour.
    // Slot 1 = amber. Slot 2 = green.
    isOn = (now % 2000UL) < 120UL;
  } else if (currentState == PAIRED && heartbeatTimedOut) {
    // Paired but vehicle heartbeat missing: alternate selected slot colour with red.
    if ((now / 500UL) % 2UL != 0UL) {
      r = 255;
      g = 0;
      b = 0;
    }
  }

  if (isOn) {
    pixel.setPixelColor(0, pixel.Color(r, g, b));
  } else {
    pixel.setPixelColor(0, pixel.Color(0, 0, 0));
  }

  pixel.show();
}
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

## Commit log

2026-04-19 Handle low battery better
    Added crash counter to handle brownout resets and prevent repeated crashes.
    Reduced LED brightness significantly.
    [MiniTroller.ino]
2026-04-19 Enhance README with detailed project information
    Expanded project description and added links to original design and STL files.
2026-04-19 Update motor PWM configuration for left motor
